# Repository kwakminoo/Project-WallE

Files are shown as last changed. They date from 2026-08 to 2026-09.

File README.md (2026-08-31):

# Project-WallE / 월이(WOLI)

스마트폰을 로봇 머리에 거치하면 집중 모드로 전환되는 **디지털 디톡스 로봇** 프로젝트입니다.  
중요한 연락은 남기고, 불필요한 연결만 잠시 끊도록 돕는 집중 동반 로봇입니다.

> 슬로건: **집중할 땐 함께, 쉴 땐 자유롭게.**

---

## 프로젝트 한눈에 보기

| 구분 | 내용 |
|---|---|
| 제품명 | 월이 (WOLI) |
| 앱 | Android (Kotlin + Jetpack Compose) |
| 펌웨어 | ESP32 (Arduino / PlatformIO, NimBLE) |
| 통신 | BLE (Bluetooth Low Energy) |
| 현재 단계 | **1차 기능 완성 + 실기기 검증 보강 단계** — 중요 연락처, 음성 명령, 백그라운드 집중 보호, BLE 잠금/캘리브레이션, 하드웨어 진단 화면까지 구현 |

### 핵심 아이디어

1. 앱에서 집중 시간·중요 연락처를 설정한다.
2. 스마트폰을 월이 머리 거치대에 **가로**로 올린다.
3. BLE 연결 후 물리적 잠금이 작동하고, 화면은 **눈만 보이는 집중 모드**가 된다.
4. 중요 연락·손 접근 시에만 표정/TTS로 안내하고, 음성으로 답장/전화 제어를 시도한다.
5. 중도 해제 시 리듬 미션 등 마찰 장치를 거친다.

자세한 기획은 루트의 `디지털_디톡스_로봇_월이_기획안.md`와 `SW 예 상시나리오.png`를 참고하세요.

---

## 현 화면 상태

에뮬레이터(Pixel_9a)에서 캡처한 초기 화면입니다. 현재 코드는 캡처 이후 알림/답장/전화 감지/BLE/타이머 기능이 추가된 상태입니다.
원본 이미지는 [`docs/screenshots/`](docs/screenshots/)에 있습니다.

### 세로 — 집중 전

| 화면 | 미리보기 |
|---|---|
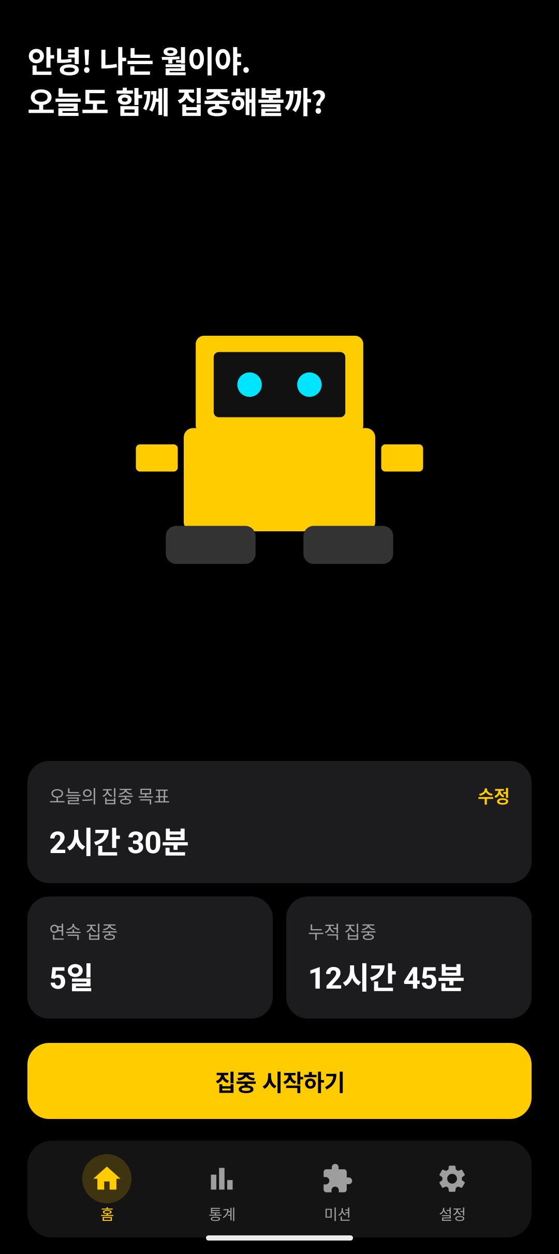
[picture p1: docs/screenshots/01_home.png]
홈
| 홈 |  |
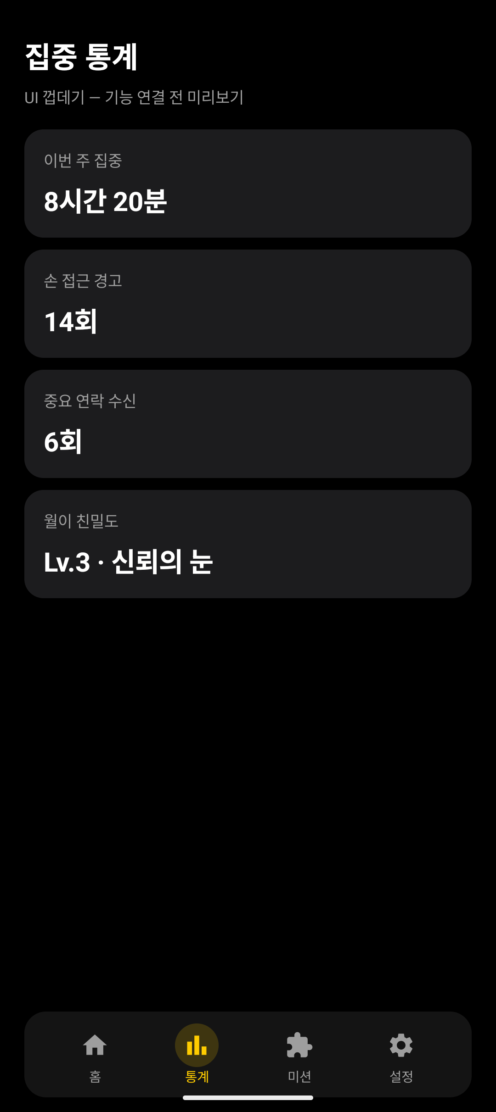
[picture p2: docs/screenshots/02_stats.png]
통계
| 통계 |  |
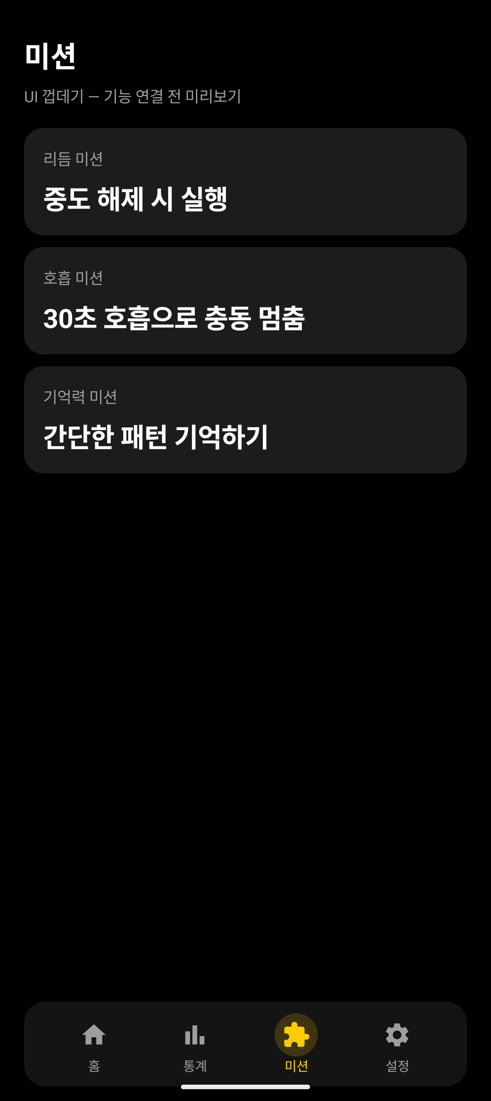
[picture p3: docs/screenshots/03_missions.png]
미션
| 미션 |  |
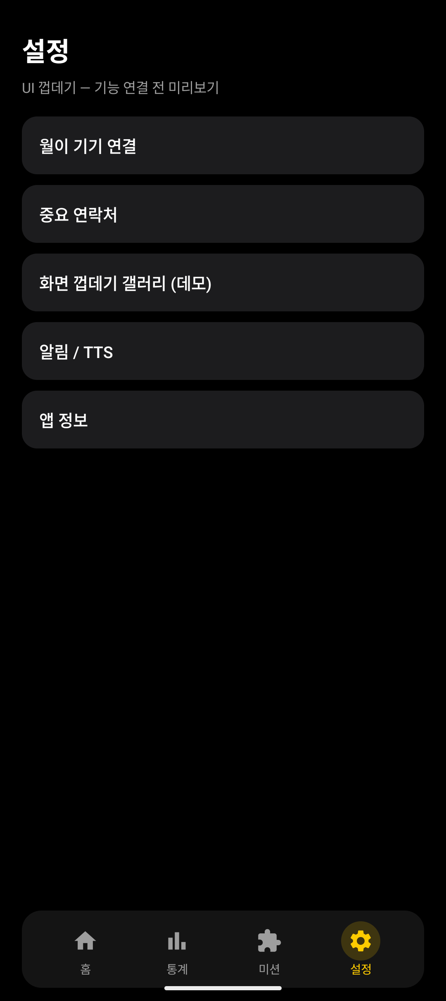
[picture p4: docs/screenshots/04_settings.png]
설정
| 설정 |  |
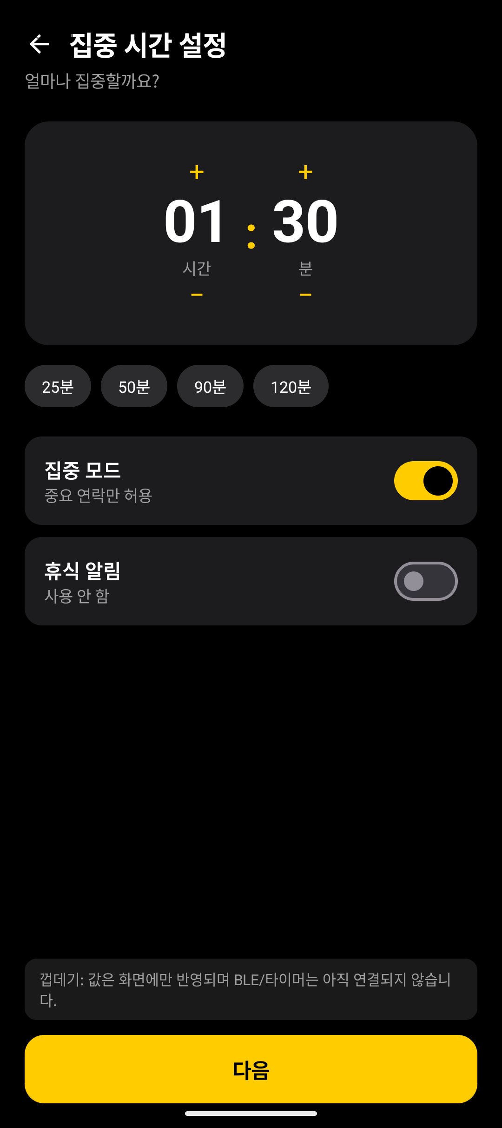
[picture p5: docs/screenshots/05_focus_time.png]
집중 시간 설정
| 집중 시간 설정 |  |
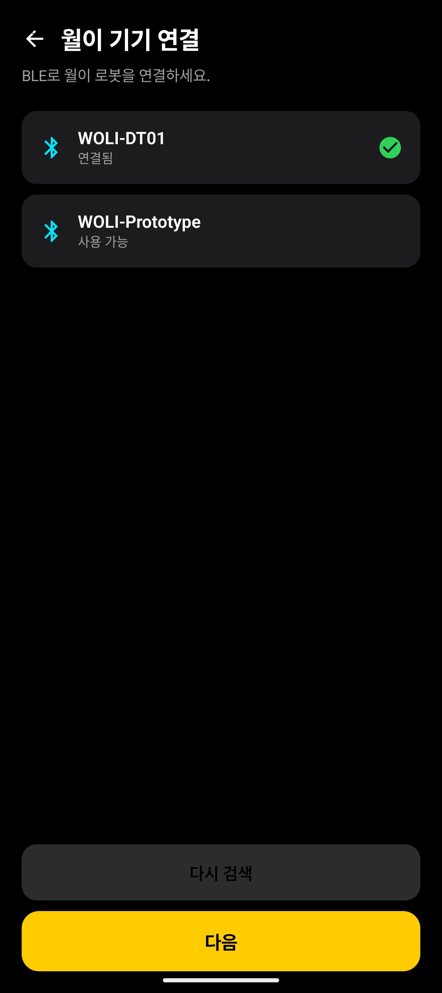
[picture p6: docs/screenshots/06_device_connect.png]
월이 기기 연결
| 월이 기기 연결 |  |
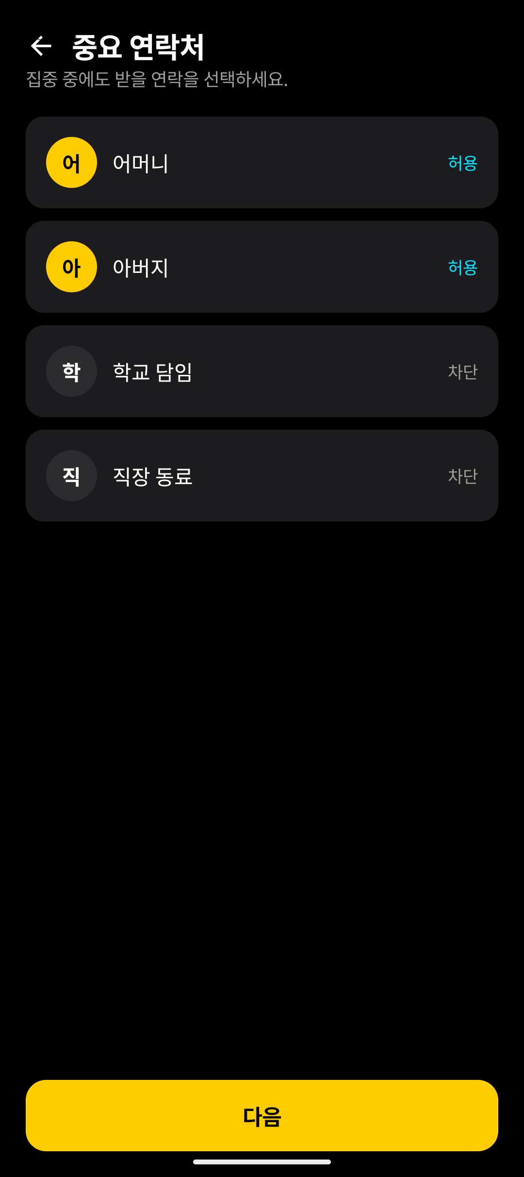
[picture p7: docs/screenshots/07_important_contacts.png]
중요 연락처
| 중요 연락처 |  |
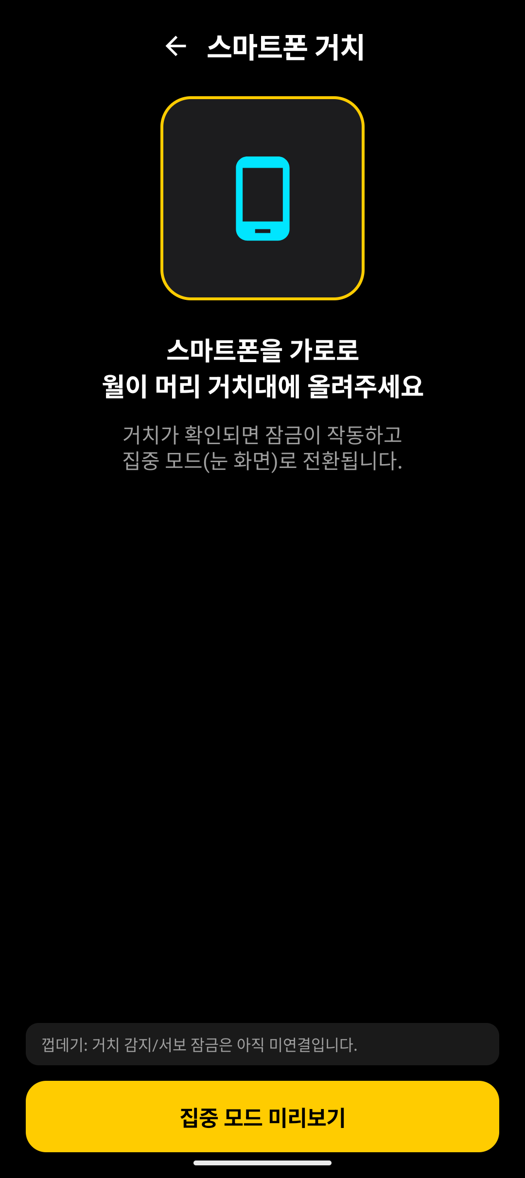
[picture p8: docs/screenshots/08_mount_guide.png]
스마트폰 거치 안내
| 스마트폰 거치 안내 |  |
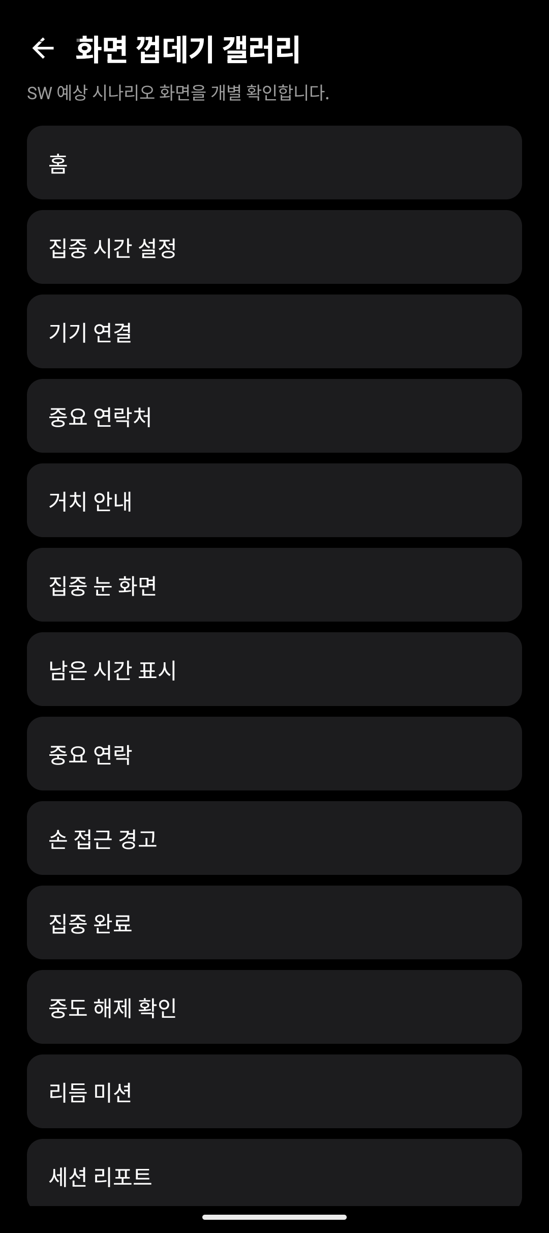
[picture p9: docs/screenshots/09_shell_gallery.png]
화면 상태 갤러리
| 화면 상태 갤러리 |  |

### 집중 모드 · 이벤트

| 화면 | 미리보기 |
|---|---|
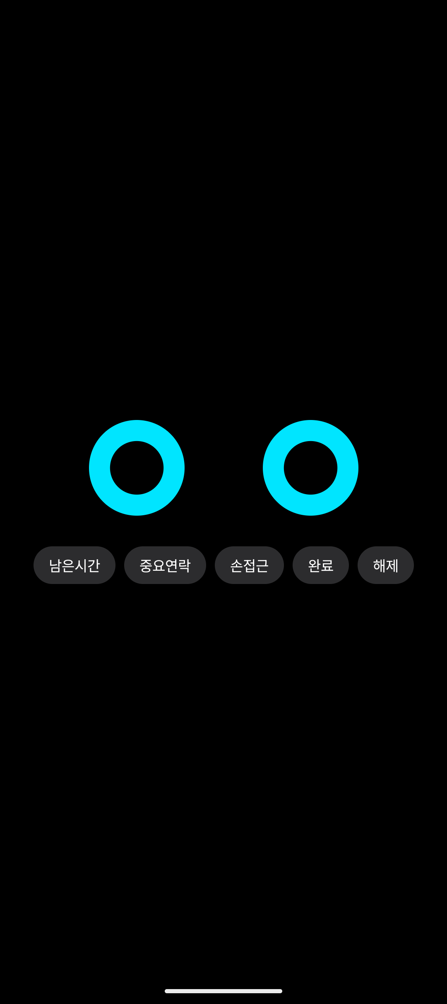
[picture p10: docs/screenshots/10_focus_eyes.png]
집중 눈 화면
| 집중 눈 화면 |  |
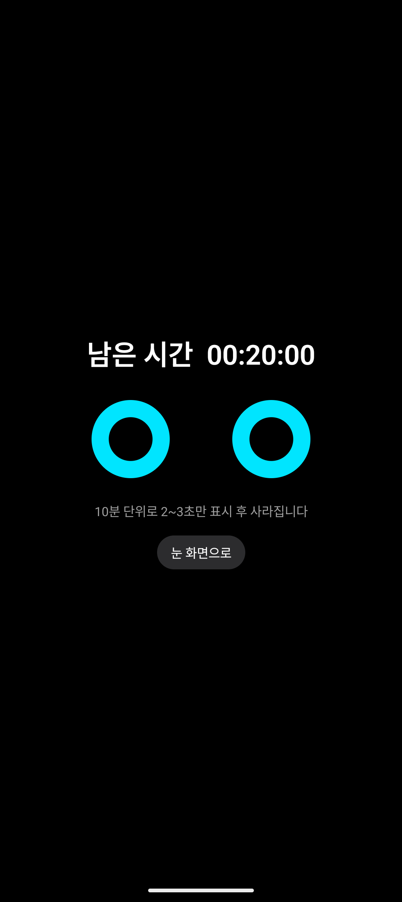
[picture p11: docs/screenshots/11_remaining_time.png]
남은 시간 표시
| 남은 시간 표시 |  |
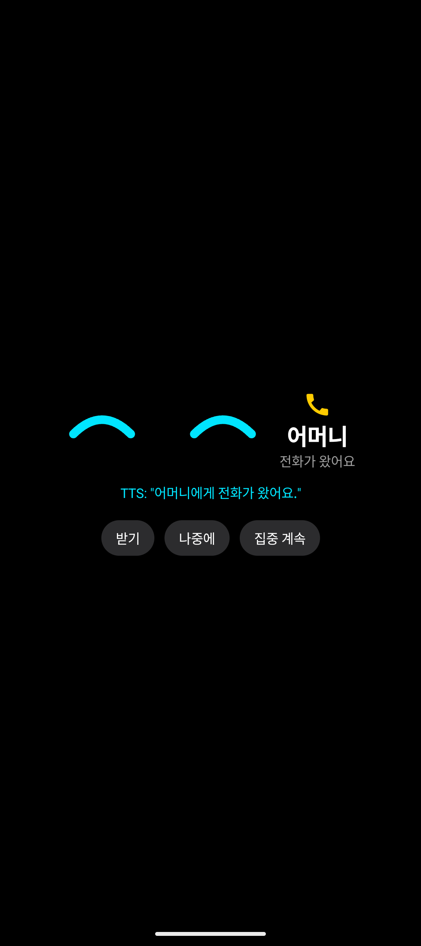
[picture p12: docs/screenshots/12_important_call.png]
중요 연락
| 중요 연락 |  |
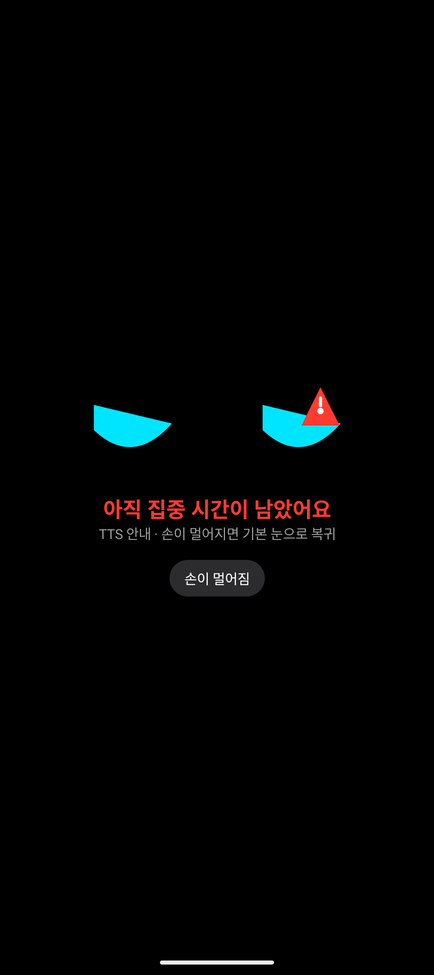
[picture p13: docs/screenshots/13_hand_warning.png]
손 접근 경고
| 손 접근 경고 |  |
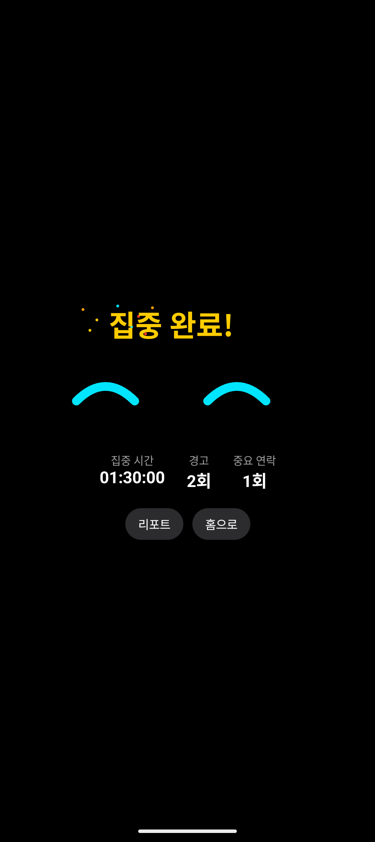
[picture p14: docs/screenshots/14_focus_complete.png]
집중 완료
| 집중 완료 |  |
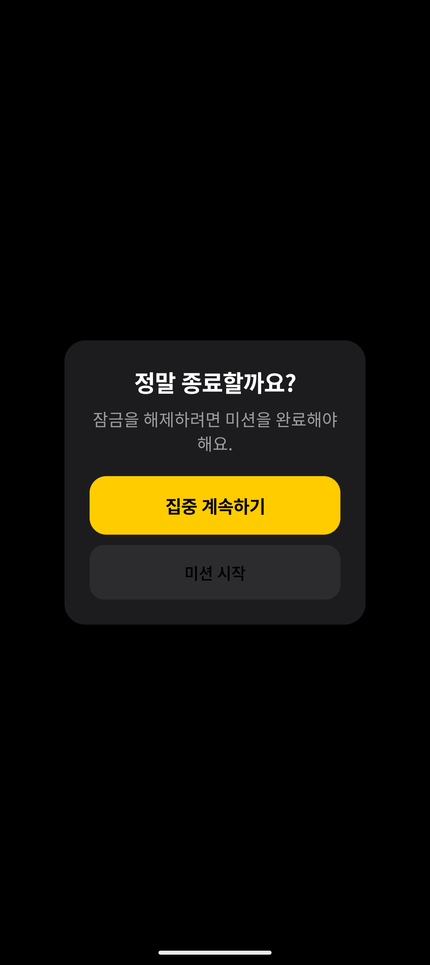
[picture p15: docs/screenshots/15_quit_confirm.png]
중도 해제 확인
| 중도 해제 확인 |  |
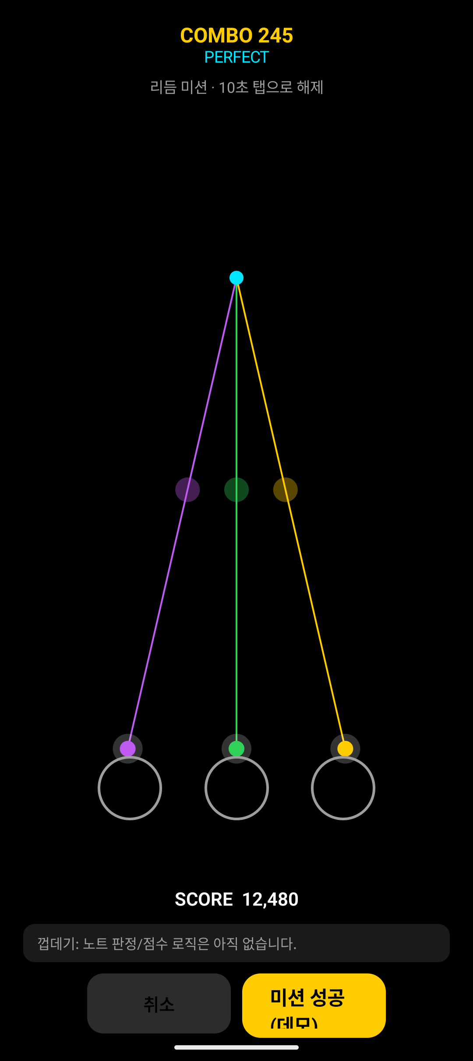
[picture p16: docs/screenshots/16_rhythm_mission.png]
리듬 미션
| 리듬 미션 |  |
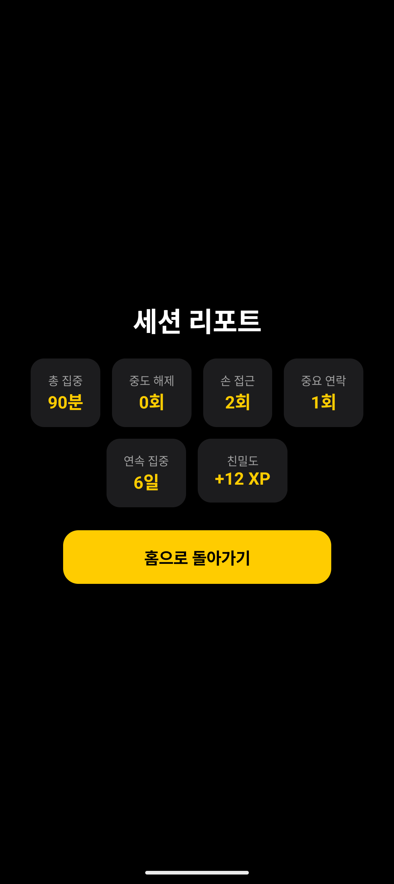
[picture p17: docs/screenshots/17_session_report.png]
세션 리포트
| 세션 리포트 |  |

---

## 저장소 구조

```text
Project-WallE/
├── android/                 # Android 앱 (Compose + 알림/전화/BLE/세션 로직)
├── firmware/                # ESP32 PlatformIO BLE GATT 펌웨어
├── docs/screenshots/        # 현 화면 상태 캡처
├── docs/RELEASE_CHECKLIST.md # APK/펌웨어 릴리즈 전 검증 항목
├── docs/PRIVACY_NOTICE.md    # 개인정보·권한 사용 안내
├── docs/DEMO_CHECKLIST.md    # 3-5분 발표/시연 순서
├── docs/ESP32_BLE_HARDWARE_TEST.md # ESP32 BLE 실기기·nRF Connect 검증
├── 디지털_디톡스_로봇_월이_기획안.md
├── SW 예 상시나리오.png
├── HW 구상도.png
├── 월E 구상도.png
└── README.md
```

---

## 개발 시작하기 (처음 clone 한 경우)

### 0) 공통

- Git, GitHub 계정
- 이 저장소 clone:

```bash
git clone https://github.com/kwakminoo/Project-WallE.git
cd Project-WallE
```

### 1) Android 앱

#### 필수 설치

1. **JDK 17** (Temurin / Oracle 등)
2. **Android Studio** (권장: Ladybug 이상) 또는 Android SDK Command-line Tools
3. Android SDK
   - `platforms;android-36` (또는 35+)
   - `build-tools;35.0.0` 이상
   - Platform-Tools

#### SDK 경로 설정

`android/local.properties` 파일을 만들고 SDK 경로를 적습니다.  
(이 파일은 git에 올리지 않습니다.)

```properties
sdk.dir=C\:\\Users\\<YOU>\\AppData\\Local\\Android\\Sdk
```

macOS/Linux 예:

```properties
sdk.dir=/Users/<YOU>/Library/Android/sdk
```

#### 의존성 / 패키지 (Gradle이 자동 다운로드)

앱 모듈(`android/app/build.gradle.kts`)에 포함된 주요 의존성:

| 용도 | 패키지 |
|---|---|
| UI | Jetpack Compose BOM, Material3, Material Icons |
| 네비게이션 | `androidx.navigation:navigation-compose` |
| 생명주기 | `lifecycle-runtime-ktx`, `lifecycle-viewmodel-compose` |
| 로컬 저장 | SharedPreferences 기반 집중 세션, 중요 연락처, 답장 이력 |
| 비동기 | `kotlinx-coroutines-android` |
| BLE | Android BLE scan/connect + WOLI GATT command/status/session/calibration |

설치/동기화:

```bash
cd android
.\gradlew.bat :app:testDebugUnitTest
.\gradlew.bat :app:assembleDebug
.\gradlew.bat lint
```

Android Studio를 쓰는 경우:

1. **Open** → `Project-WallE/android` 폴더 선택
2. Gradle Sync 완료 대기
3. 에뮬레이터 또는 실기기에서 `app` Run

#### 구현된 앱 기능

- 집중 시간 설정과 실제 세션 타이머
- 중요 연락처 수동 저장, 단말 연락처 불러오기, 이름/번호 기반 중요도 매칭
- Android 알림 접근 기반 중요 알림 감지/TTS
- `집중 우선 / 균형 / 시연` 모드 기반 알림 판단 정책
- 일반 카카오톡/문자/DM 기본 제외, 중요 연락처·긴급 표현·허용 앱만 안내
- 답장 가능한 알림의 음성 인식 초안 생성, 음성 명령, RemoteInput 전송
- 답장 전송 이력 저장과 앱별 검증 대시보드
- 전화 수신 상태 감지, 발신자 best-effort 식별, TTS 안내, 받기/거절 API 시도
- Foreground Service 기반 백그라운드 집중 보호
- Android 13+ 포그라운드 알림 권한과 배터리 최적화 상태 점검
- BLE 월이 기기 검색/연결, 시뮬레이션 연결, status 동기화, `START`/`SESSION_END`/잠금/캘리브레이션 명령
- 설정 화면의 하드웨어 검증 도구
- 거치/잠금/손 접근 상태 반영
- 리듬/호흡/기억력 미션
- 세션 완료 리포트와 통계 일부 실제 데이터 반영

### 2) ESP32 펌웨어

#### 필수 설치

1. [VS Code](https://code.visualstudio.com/) + **PlatformIO** 확장  
   또는 [PlatformIO Core CLI](https://platformio.org/install/cli)
2. USB 드라이버 (보드에 따라 CP210x / CH340)

#### 의존성

`firmware/platformio.ini` 기준:

- platform: `espressif32`
- board: `esp32dev` (ESP32-WROOM-32)
- framework: `arduino`
- lib: `h2zero/NimBLE-Arduino`, `madhephaestus/ESP32Servo`

빌드/업로드:

```bash
cd firmware
pio pkg install
pio run
pio run -t upload
pio device monitor
```

현재 `src/main.cpp`는 WOLI BLE GATT 서버를 실행합니다.

| 항목 | 값 |
|---|---|
| BLE 이름 | `WOLI-DT01` |
| Service UUID | `7e7a0001-1f5f-4c2b-9b6f-2d1b7f4f0100` |
| Command UUID | `7e7a0002-1f5f-4c2b-9b6f-2d1b7f4f0100` |
| Status UUID | `7e7a0003-1f5f-4c2b-9b6f-2d1b7f4f0100` |
| Commands | `LOCK`, `UNLOCK`, `START`, `SESSION_END`, `STOP`, `STATUS`, `CAL_LOCK=90`, `CAL_UNLOCK=10` |
| Status payload | `mount=1;lock=1;hand=0;battery=100;session=1` |

`START`는 집중 세션과 잠금을 활성화하고, 정상 완료의 `SESSION_END`는 세션을 비활성화하고 잠금을 풉니다. Status Characteristic은 READ + NOTIFY이며 `session`은 집중 세션 활성 상태(0/1)입니다.

ESP32 핀 연결, Android 실기기 절차, 재연결, nRF Connect 분리 검증은 [ESP32 BLE 실기기 검증](docs/ESP32_BLE_HARDWARE_TEST.md)을 따르세요.

### 3) (선택) 설계 도구

| 영역 | 도구 |
|---|---|
| UI·UX | Figma |
| 3D 모델링 | Fusion 360 / Onshape |
| 렌더링 | Blender |

---

## MVP 범위 (참고)

**1차 MVP:** 앱 실행, 집중 시간, BLE, 서보 잠금, 눈 화면, 남은 시간 표시, 중요 알림/전화, 음성 답장/명령, 완료/리포트

**현재 저장소:** 1차 MVP 소프트웨어 구현 + ESP32 BLE GATT/Servo 펌웨어 + 기획 문서

### 실기기 검증 체크리스트

- 설정 > 집중 알림 기준에서 `균형` 모드와 허용 앱 상태 확인
- Android 실기기에서 카카오톡/문자/Telegram/WhatsApp 답장 성공 여부 확인
- 일반 메신저 알림은 제외되고 중요 연락처/긴급 알림만 TTS 안내되는지 확인
- Android 제조사별 발신자 번호 전달, 전화 받기/거절 API 허용 여부 확인
- 실제 서보 각도, 리미트 스위치, 손 접근 센서 핀/전기적 안정성 캘리브레이션
- 실제 BLE `START`/`SESSION_END`, Status Notify, 연결 해제 후 상태 재동기화 검증
- Foreground Service 알림 권한과 배터리 최적화 예외 동작 확인
- 최신 UI 상태에 맞춘 스크린샷 재촬영

자세한 제출 전 점검은 [`docs/RELEASE_CHECKLIST.md`](docs/RELEASE_CHECKLIST.md), [ESP32 BLE 실기기 검증](docs/ESP32_BLE_HARDWARE_TEST.md), 알림 판단 기준은 [`docs/NOTIFICATION_POLICY.md`](docs/NOTIFICATION_POLICY.md), 개인정보 안내는 [`docs/PRIVACY_NOTICE.md`](docs/PRIVACY_NOTICE.md), 시연 흐름은 [`docs/DEMO_CHECKLIST.md`](docs/DEMO_CHECKLIST.md)를 확인하세요.

---

## GitHub

- 원격 저장소: https://github.com/kwakminoo/Project-WallE

대용량/비관련 파일(`TNC Web Re.zip` 등)은 `.gitignore`로 제외합니다.

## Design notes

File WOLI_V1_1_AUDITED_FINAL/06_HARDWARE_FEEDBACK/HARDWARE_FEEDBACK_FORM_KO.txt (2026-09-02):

WOLI V1.1 HARDWARE FEEDBACK FORM
================================

DATE:
PRINTER:
FILAMENT:
LAYER:

A. MAIN CHASSIS / MOTOR
N20 bracket fit: PASS / FAIL
Wheel free rotation: PASS / FAIL
Actual ground clearance:
Photo:

B. BATTERY
Tray fit: PASS / FAIL
68×143×11 battery fit: PASS / FAIL
Port access: PASS / FAIL
Correction mm:
Photo:

C. CASTER
Clip-fit: PASS / FAIL
Retainer: PASS / FAIL
Ball free rotation: PASS / FAIL
Ground contact with both drive wheels: PASS / FAIL
Shim: 0 / 1 / 2 / 3mm
Photo:

D. TOP COVER / TOF
Skirt insertion: PASS / FAIL
Side screws: PASS / FAIL
ToF opening alignment: PASS / FAIL
Wire pinch: PASS / FAIL

E. PHONE BALL
Diameter:
Fit:
Sag:
Photo:

F. SERVO LOCK
Horn photo:
Horn hole/screw:
Chosen reach:
LOCK:
UNLOCK:
Stall:
Interference:

G. ELECTRONICS
PCB tray:
TB6612 tray:
USB holder:
USB hatch if tested:

H. STABILITY
Phone model:
Approx phone mass:
Standing:
Driving:
Hard stop:
Turning:

I. ERROR
File:
Symptom:
Actual mm:
CAD mm:
Requested change:
Photo:

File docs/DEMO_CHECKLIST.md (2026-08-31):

# WOLI 시연 체크리스트

3-5분 발표 기준의 안정적인 데모 순서입니다.

## 1. 시작 전

- [ ] 테스트 연락처를 중요 연락처에 저장한다.
- [ ] 설정 > 집중 알림 기준에서 `균형` 모드를 선택한다.
- [ ] 답장 시연까지 필요하면 허용 앱 또는 `시연` 모드를 준비한다.
- [ ] 테스트 메시지 앱에서 알림이 뜨도록 준비한다.
- [ ] 앱 설정 > 알림 / TTS 검증에서 알림 접근과 TTS 상태를 확인한다.
- [ ] 앱 설정 > 하드웨어 검증에서 ESP32 또는 시뮬레이션 연결을 확인한다.
- [ ] 서보 잠금/해제 각도가 안전한지 확인한다.
- [ ] 실기기 시연이면 [ESP32 BLE 실기기 검증](ESP32_BLE_HARDWARE_TEST.md)의 배선과 STATUS 동기화를 먼저 확인한다.

## 2. 발표 흐름

1. 홈에서 오늘의 집중 목표를 보여준다.
2. 집중 시간을 25분 또는 50분으로 설정한다.
3. 월이 기기를 연결하거나 시뮬레이션으로 연결한다.
4. 중요 연락처를 보여주고, 집중 중 허용할 연락만 남긴다는 점을 설명한다.
5. 설정 > 집중 알림 기준에서 일반 메신저는 제외되고 중요 연락처/긴급/허용 앱만 안내된다고 설명한다.
6. 집중 알림 전달 화면에서 알림 접근, 포그라운드 알림, 전화 권한 상태를 확인한다.
7. 하드웨어 검증 화면에서 `STATUS`와 mount/lock/hand/battery/session 상태를 보여준다.
8. 스마트폰 거치 입력을 바꿔 `mount=1` Notify가 반영되는 것을 보여준다.
9. 짧은 시연 세션을 시작해 `START` 뒤 `lock=1`, `session=1`과 집중 눈 화면을 보여준다.
10. 테스트 알림 또는 전화 이벤트를 발생시켜 TTS 안내와 답장/전화 제어 흐름을 보여준다.
11. 손 접근 입력을 한 번 감지해 경고 화면과 손 접근 횟수 +1을 보여주고, 감지를 유지해도 횟수가 더 늘지 않는 것을 보여준다.
12. 손 접근을 해제해 `hand=0` Notify 뒤 기본 집중 눈 화면으로 자동 복귀하는 것을 보여준다.
13. 정상 완료 시 `SESSION_END` 뒤 `lock=0`, `session=0`, 집중 완료 화면과 세션 리포트를 보여준다. 중도 종료는 기존 미션 흐름으로만 설명한다.

## 3. 실패 대비

- ESP32 연결 실패: 설정 > 하드웨어 검증에서 `WOLI-Simulator`로 연결한다.
- 메시지 답장 실패: 설정 > 알림 / TTS 검증에서 앱별 성공/실패 이력을 보여준다.
- 일반 메신저가 안내되지 않음: 설정 > 집중 알림 기준에서 허용 앱 또는 `시연` 모드를 켠다.
- 전화 제어 실패: Android 정책상 일부 기기에서 best-effort라고 설명하고 수신 감지/TTS 안내를 중심으로 시연한다.
- 알림 미수신: 알림 접근 설정과 앱 알림 설정을 다시 열어 확인한다.
- TTS 출력 실패: 기기 볼륨과 미디어 출력 장치를 확인하고, 화면 이벤트 흐름으로 대체한다.
- BLE 연결 해제: `WOLI-DT01`을 다시 검색해 연결한 뒤 하드웨어 검증의 `STATUS`로 실제 상태를 다시 동기화한다. 시뮬레이션은 실기기 BLE/센서 검증의 대체 증거가 아니다.

## 4. 심사위원에게 강조할 포인트

- 집중을 방해하는 스마트폰 자체를 물리적으로 멀리 두는 로봇형 UX
- 모든 연락을 차단하지 않고 중요한 연락만 선별하는 현실적인 디지털 디톡스
- 일반 카톡/문자를 기본 제외해 집중 목적을 해치지 않는 알림 정책
- 알림, 전화, BLE, 서보, 센서 상태가 하나의 집중 세션으로 연결되는 점
- Android 정책 차이를 앱별 검증 대시보드와 시뮬레이션 경로로 투명하게 다루는 점

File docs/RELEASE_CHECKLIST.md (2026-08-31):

# WOLI 1차 릴리즈 체크리스트

월이 앱과 ESP32 펌웨어를 시연 가능한 상태로 고정하기 위한 체크리스트입니다.

## 1. Android 빌드

- [ ] `android/local.properties`에 실제 Android SDK 경로가 있다.
- [ ] 디버그 빌드가 성공한다.

```bash
cd android
.\gradlew.bat :app:testDebugUnitTest
.\gradlew.bat :app:assembleDebug
.\gradlew.bat lint
```

macOS/Linux에서는 `./gradlew :app:testDebugUnitTest :app:assembleDebug lint`를 사용합니다.

- [ ] APK 위치를 확인한다.

```text
android/app/build/outputs/apk/debug/app-debug.apk
```

## 2. 릴리즈 서명

`local.properties`나 환경 변수로만 서명 정보를 관리하고, 키스토어와 비밀번호는 git에 올리지 않습니다.

권장 환경 변수:

```bash
export WOLI_STORE_FILE=/absolute/path/woli-release.jks
export WOLI_STORE_PASSWORD=...
export WOLI_KEY_ALIAS=woli
export WOLI_KEY_PASSWORD=...
```

릴리즈 빌드 설정을 추가한 뒤 다음 명령으로 확인합니다.

```bash
cd android
./gradlew :app:assembleRelease
```

## 3. Android 실기기 권한

- [ ] 알림 접근: 설정 > 알림 접근 > 월이 허용
- [ ] 앱 알림: Android 13 이상에서 월이 알림 허용
- [ ] 배터리 제한: 설정 > 배터리 최적화에서 월이를 제한 없음 또는 예외로 설정
- [ ] 전화 감지: 전화 상태 권한 허용
- [ ] 발신자 식별: 통화 기록 권한은 기기/OS 정책에 따라 선택 허용
- [ ] 전화 제어: 받기/거절 API가 허용되는 기기에서만 검증
- [ ] 연락처: 중요 연락처 매칭에 필요한 경우만 허용
- [ ] Bluetooth: ESP32 실기기 연결 전 허용

앱 내부 확인 위치:

- 설정 > 집중 알림 기준
- 설정 > 알림 / TTS 검증
- 설정 > 하드웨어 검증
- 집중 시작 플로우 > 집중 알림 전달

## 4. 앱별 답장 검증

앱마다 RemoteInput 지원 방식이 다릅니다. 아래는 실기기에서 직접 확인해야 합니다.

- [ ] SMS 또는 기본 메시지 앱
- [ ] KakaoTalk
- [ ] Telegram
- [ ] WhatsApp

검증 기준:

- [ ] 설정 > 집중 알림 기준 기본값이 `균형` 모드로 표시된다.
- [ ] 일반 카카오톡/문자/DM은 기본적으로 TTS 안내되지 않는다.
- [ ] 중요 연락처의 카카오톡/문자/DM은 TTS 안내된다.
- [ ] 중요 연락처 + 긴급 표현 메시지는 긴급 알림으로 표시된다.
- [ ] 광고/쿠폰/좋아요/댓글/묶음/재생 중 알림은 TTS 안내되지 않는다.
- [ ] `시연` 모드에서 답장 가능한 테스트 메시지가 안내된다.
- [ ] 알림 제목/본문이 개인정보 마스킹 없이 과도하게 저장되지 않는다.
- [ ] 월이가 TTS로 중요 알림만 안내한다.
- [ ] 음성 명령 `답장`, `보내`, `취소`가 의도대로 동작한다.
- [ ] 전송 성공/실패가 설정 > 알림 / TTS 검증에 남는다.

## 5. ESP32 펌웨어

- [ ] PlatformIO가 설치되어 있다.
- [ ] 빌드가 성공한다.

```bash
cd firmware
pio pkg install
pio run
```

- [ ] 업로드가 성공한다.

```bash
pio run -t upload
pio device monitor
```

- [ ] BLE 이름이 `WOLI-DT01`로 보인다.
- [ ] 앱의 설정 > 하드웨어 검증에서 `STATUS`, `LOCK`, `UNLOCK`, `START`, `SESSION_END`, `CAL_LOCK`, `CAL_UNLOCK` 명령이 동작한다.
- [ ] `START` 후 Status가 `lock=1;session=1`을, 정상 완료의 `SESSION_END` 후 `lock=0;session=0`을 보고한다.
- [ ] Status Characteristic의 READ + NOTIFY로 mount/lock/hand/battery/session이 실제 상태와 일치한다.
- [ ] GPIO 19 거치 입력과 GPIO 21 손 접근 입력이 debounce 후 즉시 Notify된다. 손을 유지해도 세션 경고 횟수는 증가하지 않고, 손을 떼면 집중 눈 화면으로 복귀한다.
- [ ] 집중 중 연결을 끊고 다시 연결한 뒤 `STATUS` 동기화가 정상이며 앱 타이머/세션 기록이 유지된다.
- [ ] nRF Connect에서 Command Write와 Status Read + Notify를 별도로 확인했다.

세부 배선, 안전 주의, STEP 1–15, nRF Connect 절차는 [ESP32 BLE 실기기 검증](ESP32_BLE_HARDWARE_TEST.md)을 따른다.

## 6. 시연 전 고정

- [ ] 스마트폰 1대, 예비 스마트폰 1대, USB-C 케이블, 보조배터리를 준비한다.
- [ ] ESP32 전원 공급이 흔들리지 않는다.
- [ ] 서보 잠금 각도가 스마트폰을 무리하게 누르지 않는다.
- [ ] 발표용 연락처와 테스트 메시지만 사용한다.
- [ ] 개인정보가 들어간 실제 알림은 방해 금지 또는 별도 계정으로 차단한다.
- [ ] 네트워크가 없어도 핵심 시연이 가능한 시뮬레이션 경로를 준비한다.

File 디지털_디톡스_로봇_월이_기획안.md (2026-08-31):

# 디지털 디톡스 로봇 ‘월이(WOLI)’ 기획안

> **한 줄 정의**  
> 스마트폰을 빼앗는 장치가 아니라, 중요한 연결은 남기고 불필요한 연결만 잠시 끊어주는 집중 동반 로봇

---

## 1. 프로젝트 개요

‘월이’는 스마트폰을 로봇 머리 부분의 거치대에 장착하면 전용 앱이 자동으로 집중 모드로 전환되는 디지털 디톡스 로봇이다.  
사용자는 집중 시간을 설정하고 스마트폰을 가로 방향으로 거치한다. 집중 중에는 스마트폰 화면이 월이의 얼굴이 되어 눈 모양만 표시되며, 중요한 연락이나 손 접근 상황에서만 표정과 음성 안내가 나타난다.

월이의 핵심은 별도의 디스플레이·마이크·스피커를 추가하지 않고 스마트폰의 화면, 전면 카메라, 근접 감지 기능, 마이크, 스피커, 알림 기능을 그대로 활용하는 것이다. 로봇 하드웨어는 스마트폰 거치, 물리적 잠금, BLE 연결, 전원 공급 등 최소 기능을 담당하며, 이번 실기기 검증 단계에서는 거치·손 접근 상태를 ESP32의 교체 가능한 디지털 입력으로 앱에 전달한다.

---

## 2. 문제 정의

스마트폰 사용자는 공부나 업무를 시작한 뒤에도 SNS, 메신저, 짧은 영상, 게임, 반복적인 알림 확인으로 인해 집중 흐름이 쉽게 끊긴다.

기존 집중 앱은 사용자가 직접 앱을 종료하거나 다른 앱으로 이동할 수 있어 통제력이 약하다. 반대로 타이머형 잠금 상자는 스마트폰을 완전히 차단하기 때문에 긴급 전화나 중요한 알림까지 놓칠 수 있다. 또한 단순한 차단 방식은 사용자가 집중을 ‘통제’로 인식하게 만들어 장기적인 습관 형성으로 이어지기 어렵다.

월이는 다음 문제를 해결한다.

- 앱만으로는 부족한 자기 통제
- 긴급 연락까지 차단되는 불안
- 집중 시간 중 반복적으로 스마트폰에 손을 대는 습관
- 집중 앱의 낮은 지속 사용 동기
- 단순 타이머가 제공하지 못하는 감정적 상호작용

---

## 3. 고객 타깃층

### 3.1 핵심 타깃

#### 학생·수험생
- 공부 중 SNS와 영상 앱을 반복적으로 확인하는 사용자
- 25분~120분 단위로 집중 시간을 관리하는 사용자
- 일반 타이머보다 캐릭터와 시각적 피드백을 선호하는 사용자

#### 직장인·재택근무자·프리랜서
- 문서 작성, 코딩, 디자인 등 몰입 업무가 필요한 사용자
- 업무 중 메신저와 알림 때문에 집중이 자주 끊기는 사용자
- 중요한 연락만 놓치지 않고 싶은 사용자

#### 디지털 웰니스 관심 사용자
- 자기 전 스마트폰 사용을 줄이려는 사용자
- 독서, 운동, 명상 등 오프라인 습관을 만들고 싶은 사용자
- 디지털 디톡스를 강제 차단이 아닌 재미있는 경험으로 만들고 싶은 사용자

### 3.2 확장 타깃

- 스터디카페 및 도서관
- 기업 사내 집중·웰니스 프로그램
- 부모와 자녀가 함께 사용하는 가정용 집중 기기
- 학교 자기주도학습 프로그램

---

## 4. 핵심 기능

### 4.1 스마트폰 거치 및 자동 집중 모드

사용자가 앱에서 집중 시간을 설정한 뒤 스마트폰을 월이의 머리 부분에 가로로 거치하면 집중 모드가 시작된다.

- 앱 실행
- 집중 시간 설정
- 스마트폰 가로 거치
- BLE 연결 확인
- 집중 모드 자동 시작
- 물리적 잠금 작동

### 4.2 월이 얼굴 화면

집중 모드에서는 스마트폰 화면 전체가 검은색 배경으로 전환되고 월이의 눈만 표시된다.

#### 기본 화면
- 검은색 배경
- 청록색 또는 하늘색 눈 2개
- 타이머, 버튼, 문구는 기본적으로 숨김
- 화면을 로봇의 얼굴처럼 사용

#### 10분 단위 남은 시간 표시
집중 시간이 10분 단위로 줄어드는 순간에만 남은 시간을 짧게 표시한다.

예시:

- 50분 남음
- 40분 남음
- 30분 남음
- 20분 남음
- 10분 남음

남은 시간은 약 2~3초간 표시된 뒤 사라지고 다시 눈만 보이는 기본 화면으로 돌아간다.

### 4.3 손 접근 감지

이번 실기기 검증 단계에서는 ESP32의 디지털 손 접근 입력을 BLE `hand` 상태로 전달한다. 센서 모델은 고정하지 않으며, 스마트폰 전면 카메라·근접 센서·영상 인식은 이후 보조 입력으로 확장할 수 있다.

- 손이 가까워지면 월이의 눈이 사용자를 따라감
- 일정 거리 이상 접근하면 경계 표정 표시
- “아직 집중 시간이 남았어요”라는 음성 안내
- 손이 멀어지면 기본 눈 화면으로 복귀
- 접근 횟수를 집중 리포트에 기록

### 4.4 중요 연락 전달

사용자는 집중 시작 전에 허용 연락처와 중요 알림을 설정한다.

- 가족
- 학교 또는 직장
- 특정 연락처
- 긴급 전화
- 선택한 메신저 또는 알림 유형

중요 연락이 오면 월이는 잠시 놀란 표정으로 바뀌고 스마트폰 스피커로 내용을 안내한다.

예시:

> “어머니에게 전화가 왔어요.”

사용자는 음성 명령 또는 화면 버튼으로 다음 행동을 선택한다.

- 받기
- 나중에 확인
- 집중 계속

### 4.5 중도 해제 방지 미션

사용자가 집중 시간을 채우기 전에 스마트폰을 꺼내거나 앱을 종료하려 하면 해제 미션이 실행된다.

미션 예시:

- 리듬 게임
- 30초 호흡 미션
- 간단한 기억력 게임
- 집중 종료 이유 선택
- 긴급 해제 버튼 길게 누르기

미션은 완전한 강제 차단이 아니라 충동적인 해제를 한 번 더 생각하게 만드는 행동 마찰 장치로 사용한다.

### 4.6 집중 완료 및 리포트

집중 시간이 끝나면 월이의 눈이 웃는 표정으로 바뀌고 완료 음성이 재생된다.

제공 정보:

- 총 집중 시간
- 중도 해제 횟수
- 손 접근 횟수
- 중요 연락 수신 횟수
- 연속 집중 일수
- 일·주·월별 집중 시간
- 월이 친밀도 또는 성장 단계

---

## 5. 예상 화면 시나리오

### 5.1 세로 화면 단계

1. 홈 화면
2. 월이 기기 연결
3. 집중 시간 설정
4. 중요 연락처 설정
5. 스마트폰 거치 안내

### 5.2 가로 화면 단계

1. 집중 시작
2. 기본 눈 화면
3. 10분 단위 남은 시간 잠깐 표시
4. 중요 연락 도착
5. 손 접근 경고
6. 집중 완료
7. 중도 해제 미션
8. 세션 리포트

### 화면 방향 원칙

- 집중 시작 전: 세로 화면
- 스마트폰 거치 후: 가로 화면
- 집중 모드 이후 모든 화면: 일반적인 스마트폰 가로 비율 유지
- 집중 기본 화면: 눈만 표시
- 시간 정보: 10분 단위에서만 잠깐 표시
- 알림·경고·완료 화면: 필요한 정보만 짧게 표시

---

## 6. 기존 제품과의 차별성

| 제품 유형 | 기존 한계 | 월이의 차별점 |
|---|---|---|
| 집중 앱 | 사용자가 쉽게 종료 가능 | 스마트폰 거치와 물리적 잠금 결합 |
| 타이머 잠금 상자 | 연락과 알림을 모두 차단 | 중요한 연락만 선별 전달 |
| 포모도로 타이머 | 시간 측정 기능 중심 | 손 접근 감지, 표정, 음성, 리포트 제공 |
| 반려 로봇 | 감성 상호작용 중심 | 집중 습관 형성에 특화 |
| 스마트폰 웰빙 기능 | 기능적이지만 지속 동기가 약함 | 미션·표정·성장 요소 제공 |

### 핵심 차별화 문장

월이는 앱, 물리적 거치, 중요한 연락 전달, 캐릭터 상호작용을 결합해 디지털 디톡스를 단순한 차단이 아니라 ‘함께 집중하는 경험’으로 전환한다.

---

## 7. 시스템 구성

```mermaid
flowchart LR
    A[사용자] --> B[월이 앱]
    B --> C[집중 시간 설정]
    C --> D[스마트폰 가로 거치]
    D --> E[BLE 연결]
    E --> F[물리적 잠금]
    F --> G[집중 모드 실행]
    G --> H[눈 화면 표시]
    H --> I{이벤트 발생}
    I -->|10분 단위| J[남은 시간 잠깐 표시]
    I -->|중요 연락| K[음성·화면 전달]
    I -->|손 접근| L[경고 표정·음성]
    I -->|시간 종료| M[집중 완료]
    M --> N[리포트 저장]
```

---

## 8. 하드웨어 구성

### 8.1 필수 하드웨어

| 부품 | 역할 | 예상 단가 |
|---|---|---:|
| ESP32-WROOM-32 개발보드 | 스마트폰 앱과 BLE 통신, 잠금장치 제어 | 약 8,000~10,000원 |
| MG90S 메탈기어 서보모터 | 스마트폰 거치대 잠금·해제 | 약 4,000~6,000원 |
| 마이크로 리미트 스위치 | 스마트폰 거치 여부 확인 | 약 500~1,000원 |
| 5V 보조배터리 | ESP32와 서보모터 전원 공급 | 약 15,000~25,000원 |
| 전원 스위치·배선·커넥터 | 전원 제어 및 내부 연결 | 약 5,000~10,000원 |
| 나사·스프링·고무 패드 | 조립 및 스마트폰 보호 | 약 3,000~7,000원 |
| 3D 프린팅 케이스 | 월이 외형, 거치대, 잠금 구조 | 약 20,000~60,000원 |

### 8.2 제외 가능한 하드웨어

센서 모델을 제품 사양으로 고정하지 않는다. 실기기 검증에는 ESP32 GPIO의 교체 가능한 디지털 손 접근 입력을 사용하며, 배선과 검증 절차는 [ESP32 BLE 실기기 검증](docs/ESP32_BLE_HARDWARE_TEST.md)을 따른다. 다음 기능은 스마트폰 자체 기능을 사용하므로 별도 부품을 추가하지 않는다.

- OLED 디스플레이
- 별도 마이크
- 별도 스피커
- 별도 알림 표시 장치
- 별도 카메라

### 8.3 예상 총비용

- 전자부품 및 전원: 약 35,000~55,000원
- 3D 프린팅 케이스 포함: 약 55,000~115,000원
- 스마트폰 및 배송비 제외

> 가격은 기획 단계의 예상치이며 판매처, 배송비, 환율, 재고에 따라 달라질 수 있다.

---

## 9. 소프트웨어 구성

### 9.1 Android 앱

- 언어: Kotlin
- UI: Jetpack Compose
- 통신: Bluetooth Low Energy
- 로컬 저장: Room 또는 DataStore
- 음성 출력: Android TTS
- 음성 입력: SpeechRecognizer
- 손 접근 상태: ESP32 BLE `hand` 상태를 받아 경고·리포트에 반영
- 알림 처리: Notification Listener
- 집중 타이머: Foreground Service
- 화면 방향: 집중 모드 진입 시 Landscape 고정
- 미션: 간단한 리듬 게임 또는 기억력 게임

### 9.2 ESP32 펌웨어

- 언어: C/C++
- 개발 도구: Arduino IDE 또는 PlatformIO
- BLE 서버
- 스마트폰 거치 감지
- 디지털 손 접근 입력과 debounce
- 서보모터 잠금·해제
- 연결 상태 확인
- 비상 해제 처리
- 배터리 상태 전달

---

## 10. 개발환경

| 영역 | 개발 도구 |
|---|---|
| Android 앱 | Android Studio, Kotlin, Jetpack Compose |
| ESP32 펌웨어 | Arduino IDE 또는 VS Code + PlatformIO |
| UI·UX 설계 | Figma |
| 3D 모델링 | Fusion 360 또는 Onshape |
| 외형 렌더링 | Blender |
| 버전 관리 | GitHub |
| 테스트 | Android 실기기, ESP32 개발보드, 3D 프린팅 시제품 |

---

## 11. 앱과 로봇의 역할 분담

### 스마트폰 앱

- 월이 얼굴 표시
- 집중 시간 관리
- BLE 손 접근 이벤트의 화면·리포트 반영
- 중요 연락 필터링
- TTS·STT
- 미션 실행
- 집중 기록과 리포트 저장
- 사용자의 모든 주요 인터페이스 제공

### 로봇 하드웨어

- 스마트폰 거치
- 디지털 손 접근 상태 전달
- 스마트폰 잠금·해제
- BLE 연결
- 물리적 존재감 제공
- 캐릭터 외형 형성
- 비상 수동 해제 제공

---

## 12. MVP 개발 범위

### 1차 MVP

- Android 앱 실행
- 집중 시간 설정
- 스마트폰 가로 거치
- BLE 연결
- 서보모터 잠금·해제
- 검은 화면과 눈 애니메이션
- 10분 단위 남은 시간 표시
- 중요 전화 알림
- 집중 완료 화면
- 기본 리포트

### 2차 개발

- 전면 카메라 기반 손 접근 감지
- 음성 명령
- 중도 해제 미션
- 월이 친밀도·성장 시스템
- 집중 통계 시각화
- 사용자별 표정 설정

### 3차 확장

- iOS 앱
- 클라우드 백업
- 스터디 그룹 기능
- 가족·학교·기업용 관리자 모드
- 월이 캐릭터 스킨
- 주행 또는 고개 움직임

---

## 13. 안전 및 설계 원칙

- 전원이 끊기면 잠금이 풀리는 Fail-open 구조
- 후면 수동 해제 레버 제공
- 배터리 부족 시 자동 잠금 해제
- 긴급 전화 시 즉시 해제 가능
- 스마트폰 화면과 프레임을 보호하는 고무 패드 적용
- 다양한 스마트폰 크기를 수용하는 슬라이드형 거치대
- 집중 방해를 줄이기 위해 기본 화면에는 눈만 표시
- 사용자를 강제로 가두는 장치가 아니라 자발적 집중을 돕는 보조기기로 설계

---

## 14. 최종 핵심 시연 흐름

```mermaid
sequenceDiagram
    participant U as 사용자
    participant A as 월이 앱
    participant R as 월이 로봇

    U->>A: 집중 시간 설정
    U->>R: 스마트폰 가로 거치
    A->>R: BLE 연결 및 START 명령
    R->>R: 스마트폰 잠금
    A->>A: 눈만 보이는 집중 화면 실행
    A-->>U: 10분 단위 남은 시간 잠깐 표시
    A-->>U: 중요 연락 또는 손 접근 경고
    A->>R: 정상 집중 완료 시 SESSION_END 명령
    R->>R: 스마트폰 잠금 해제
    A-->>U: 세션 리포트 제공
```

---

## 15. 슬로건 제안

> **집중할 땐 함께, 쉴 땐 자유롭게.**

또는

> **중요한 연결은 지키고, 불필요한 연결은 잠시 안녕.**

---

## 16. 최종 정리

월이는 스마트폰을 완전히 없애는 제품이 아니라 스마트폰의 기능을 집중에 유리한 방향으로 재구성하는 제품이다. 스마트폰은 화면, 센서, 마이크, 스피커, 알림, 데이터 처리를 담당하고 로봇은 거치, 잠금, 물리적 존재감과 캐릭터 경험을 담당한다.

이 구조를 적용하면 불필요한 하드웨어를 줄이면서도 개발 비용과 제작 난도를 낮출 수 있다. 동시에 사용자는 월이의 눈과 음성을 통해 단순한 타이머보다 친근하고 지속적인 집중 경험을 얻을 수 있다.

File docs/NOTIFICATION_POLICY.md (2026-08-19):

# WOLI 집중 알림 판단 기준

월이는 모든 메신저 알림을 읽어주는 앱이 아니라, 집중 중에도 놓치면 안 되는 연락만 남기는 디지털 디톡스 보조 앱입니다.

## 기본 원칙

1. 일반 카카오톡, 문자, DM은 기본적으로 음성 안내하지 않습니다.
2. 중요 연락처에서 온 알림은 음성 안내합니다.
3. 중요 연락처 알림에 긴급 표현이 있으면 긴급 알림으로 올립니다.
4. 알람, 일정, 리마인더는 중요한 시간성 알림으로 안내합니다.
5. 광고, 쿠폰, 좋아요, 댓글, 추천, 묶음 요약, 음악 재생 중, 백그라운드 상태 알림은 안내하지 않습니다.
6. 시연이 필요할 때만 `시연` 모드로 답장 가능한 테스트 메시지를 안내합니다.

## 정책 모드

| 모드 | 목적 | 안내 대상 |
|---|---|---|
| 집중 우선 | 실제 집중 사용 | 전화, 중요 연락처, 알람/일정 |
| 균형 | 기본값, 공모전 시연과 실사용 균형 | 전화, 중요 연락처, 긴급 표현, 허용 앱 |
| 시연 | 발표 중 답장 흐름 확인 | 균형 모드 + 답장 가능한 테스트 메시지 |

기본값은 `균형`입니다. 일반 메신저는 이 모드에서도 바로 안내되지 않고, 중요 연락처, 긴급 표현, 사용자가 허용한 앱 조건 중 하나를 만족해야 합니다.

## 판단 순서

| 순서 | 조건 | 결과 |
|---|---|---|
| 1 | 전화 알림 | 긴급 |
| 2 | 사용자가 차단한 앱 | 제외 |
| 3 | 음악 재생, 다운로드, 포그라운드 서비스 등 상태 유지 알림 | 제외 |
| 4 | 묶음 요약 또는 단체 대화 알림 | 제외 |
| 5 | 광고, 쿠폰, 할인, 혜택성 알림 | 제외 |
| 6 | 좋아요, 댓글, 팔로우, 추천 등 소셜 반응 알림 | 제외 |
| 7 | 중요 연락처 + 긴급 표현 | 긴급 |
| 8 | 중요 연락처 | 중요 |
| 9 | 알람, 일정, 리마인더 | 중요 |
| 10 | 균형/시연 모드 + 긴급 표현 + 1:1 메신저 | 긴급 |
| 11 | 균형/시연 모드 + 사용자가 허용한 앱의 1:1 메시지 | 중요 |
| 12 | 시연 모드 + 답장 가능한 1:1 테스트 메시지 | 중요 |
| 13 | 일반 카톡, 문자, DM | 제외 |
| 14 | 그 외 알림 | 제외 |

## 키워드 기준

### 긴급 표현

- 긴급
- 급해
- 급한
- 응급
- 위급
- 사고
- 병원
- 119
- 경찰
- 지금 전화
- 전화해
- 빨리
- asap
- emergency
- urgent
- help

### 차단 표현

- 광고
- 쿠폰
- 할인
- 특가
- 혜택
- 적립
- 이벤트
- 무료배송
- 좋아요
- 댓글
- 팔로우
- 추천 게시물
- sale
- coupon
- discount

## 시연 권장 설정

1. 설정 > 중요 연락처에서 테스트 연락처를 등록합니다.
2. 설정 > 집중 알림 기준에서 `균형` 모드를 선택합니다.
3. 카카오톡 또는 문자 메시지는 기본적으로 제외된다고 설명합니다.
4. 중요 연락처에서 메시지를 보내 `중요 연락처` 판단 기준이 표시되는지 확인합니다.
5. 같은 연락처가 `긴급이야 지금 전화해줘` 같은 메시지를 보내면 긴급 알림으로 올라가는지 확인합니다.
6. 답장 기능까지 보여줘야 하면 `시연` 모드로 바꾸고 테스트 메시지를 보냅니다.

## 검증 매트릭스

| 입력 예시 | 기대 결과 |
|---|---|
| 어머니 카톡 `도착하면 연락줘` | 중요 |
| 어머니 카톡 `긴급이야 지금 전화해줘` | 긴급 |
| 친구 카톡 `ㅋㅋ 뭐해` | 제외 |
| 단체방 `새 메시지 12개` | 제외 |
| 문자 `[광고] 쿠폰 할인` | 제외 |
| 캘린더 `10분 뒤 회의` | 중요 |
| 음악 앱 `재생 중` | 제외 |
| 인스타그램 `좋아요를 눌렀습니다` | 제외 |
| 허용 앱 1:1 메시지 | 중요 |
| 시연 모드 답장 가능 메시지 | 중요 |

## 한계

- 앱마다 알림 제목, 본문, 단체방 여부를 Android에 제공하는 방식이 다릅니다.
- 일부 메신저는 단체방 여부를 명확히 제공하지 않을 수 있습니다.
- 실제 답장 가능 여부는 Android `RemoteInput` 제공 여부에 따라 달라집니다.
- 실기기에서 카카오톡, 문자, Telegram, WhatsApp을 각각 검증해야 최종 시연 안정성을 판단할 수 있습니다.

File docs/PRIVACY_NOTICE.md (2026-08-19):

# WOLI 개인정보 및 권한 안내

월이는 집중 중 중요한 연락만 안내하고, 사용자가 음성으로 답장 여부를 선택할 수 있도록 돕는 Android 앱입니다.

## 수집하거나 접근하는 정보

월이는 다음 정보를 단말 안에서만 사용합니다.

- 중요 연락처 이름과 전화번호
- 알림 제목, 앱 이름, 간단한 본문 요약
- 알림 판단 모드, 허용 앱, 긴급 키워드 등 집중 알림 기준 설정
- 답장 전송 성공/실패 이력
- 전화 수신 상태와 발신자 정보
- BLE 기기 연결 상태와 하드웨어 센서 상태

현재 저장소 기준으로 외부 서버, 클라우드 DB, 원격 분석 SDK로 데이터를 전송하지 않습니다.

## 권한 사용 목적

| 권한 | 목적 |
|---|---|
| 알림 접근 | 집중 중 중요 알림 감지 및 TTS 안내 |
| 알림 표시 | 포그라운드 서비스 실행 상태 표시 |
| 연락처 | 저장된 중요 연락처와 알림/전화 발신자 매칭 |
| 전화 상태 | 수신 전화 감지 |
| 통화 기록 | 가능한 기기에서 발신자 번호 식별 |
| 전화 제어 | 가능한 기기에서 받기/거절 명령 시도 |
| 마이크 | 음성 명령 및 답장 초안 입력 |
| Bluetooth | ESP32 월이 기기 검색, 연결, 잠금 명령 |
| 카메라 | 향후 시선/상태 인식 확장 대비 |

## 저장 위치와 삭제

- 중요 연락처, 집중 세션, 집중 알림 기준, 답장 이력은 앱 로컬 저장소에 저장됩니다.
- 앱을 삭제하면 로컬 데이터도 함께 삭제됩니다.
- 시연 전에는 개인 계정 대신 테스트 계정과 발표용 연락처를 사용하는 것을 권장합니다.

## 한계

- Android 제조사, OS 버전, 메시지 앱 정책에 따라 답장/전화 제어가 실패할 수 있습니다.
- 알림 접근 권한이 꺼져 있으면 월이가 메시지 내용을 알 수 없습니다.
- 배터리 최적화가 강한 기기에서는 백그라운드 TTS나 BLE 유지가 중단될 수 있습니다.

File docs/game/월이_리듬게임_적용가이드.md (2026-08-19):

# 월이 · 집중 모드 중도 해제 리듬게임 — 적용 가이드

## 무엇을 / 왜

기획안 **4.5 중도 해제 방지 미션**의 "행동 마찰 장치"를 정통 리듬게임으로 구현했습니다.
흐름은 그대로입니다: 집중 시간을 못 채운 채 종료를 시도 → `QuitConfirmScreen`("정말 종료할까요?") →
"미션 시작" → **리듬게임** → 통과해야만 물리 잠금이 풀립니다.

기존 화면은 "정해진 순서대로 레인 탭하기"라 리듬게임이 아니었습니다. 이번에 **노트가 레인을 따라
떨어지고 판정선에서 타이밍에 맞춰 탭 → Perfect/Good/Miss 판정**하는 방식으로 교체했고, 난이도는
기획 의도(충동적 해제를 한 번 더 생각하게 만드는 정도)에 맞춰 **적당한 마찰(약 20~30초, 집중해야 통과)**로 잡았습니다.

## 변경 요약 (4개 파일)

| 파일 | 상태 | 내용 |
|---|---|---|
| `focus/WoliRhythmGame.kt` | 신규 | 순수 Kotlin 게임 엔진 — 차트 생성·판정·점수·통과 규칙. 단위 테스트 대상. |
| `ui/screens/RhythmMissionScreen.kt` | 신규 | 새 Compose 화면 — 프레임 루프(withFrameNanos)·노트 렌더·레인 입력·결과 오버레이. |
| `ui/screens/FocusScreens.kt` | 수정 | 구버전 `RhythmMissionScreen` + `RhythmShellVisual` 제거(중복 선언 방지). |
| `test/.../WoliRhythmGameTest.kt` | 신규 | 엔진 단위 테스트 12개. |

> **MainActivity / 네비게이션은 손댈 필요 없습니다.** 새 화면의 시그니처가 기존과 동일
> (`RhythmMissionScreen(onSuccess, onCancel)`)하고, 같은 패키지(`com.woli.app.ui.screens`)에 있어
> `MainActivity`의 import와 `Routes.RHYTHM_MISSION` 연결이 그대로 유지됩니다.

## 적용 방법 (셋 중 하나)

### A. git 패치 — 팀 협업에 추천
```bash
cd Project-WallE
git apply --stat  rhythm-game.patch   # 무엇이 바뀌는지 미리보기
git apply --check rhythm-game.patch   # 충돌 여부 확인
git apply         rhythm-game.patch   # 적용
```
`--check`에서 충돌이 나면(= 로컬 `FocusScreens.kt`가 GitHub `main`과 다르면) 아래 B 또는 C를 쓰세요.

### B. zip 덮어쓰기 — 로컬이 `main`과 동기화된 경우
```bash
unzip -o walle-rhythm-game-files.zip -d Project-WallE
```
zip 안의 4개 파일이 저장소의 제자리에 들어갑니다.

### C. 수동 — 로컬이 많이 달라졌을 때 가장 안전
1. 신규 파일 3개를 그대로 추가: `WoliRhythmGame.kt`, `RhythmMissionScreen.kt`, `WoliRhythmGameTest.kt`.
2. `FocusScreens.kt`에서 **아래 두 함수만 통째로 삭제**:
   - `@Composable fun RhythmMissionScreen(onSuccess: () -> Unit, onCancel: () -> Unit) { ... }`
   - `@Composable private fun RhythmShellVisual(targetLane: Int) { ... }`

   두 함수를 안 지우면 같은 이름이 중복 선언되어 컴파일 에러가 납니다. (`MainActivity`는 그대로 두세요.)

## 빌드 & 테스트
```bash
cd android
./gradlew.bat :app:assembleDebug
./gradlew.bat :app:testDebugUnitTest    # 새 리듬 엔진 테스트 포함
```
집중 화면들은 가로(landscape) 라우트입니다(거치 시 가로). 에뮬레이터에서 종료 → 미션 시작으로 진입해 확인하세요.

## 동작 흐름 / 통합 지점

- **진입**: `QuitConfirmScreen`의 "미션 시작" → `Routes.RHYTHM_MISSION` → `RhythmMissionScreen`.
- **성공**(목표 성공 수 도달) 시 기존과 동일하게 호출:
  `recordMissionAttempt(success = true)` → `WoliFocusSessionController.complete(MissionUnlocked)` →
  `WoliDeviceCenter.setLocked(false)` → `WoliFocusGuardService.stop(context)` → `onSuccess()`(홈으로).
- **실패**(허용 실패치 초과 또는 노트 소진 후 목표 미달) 시:
  `recordMissionAttempt(success = false)` 후 "다시 시도 / 집중 계속하기" 오버레이 표시.
- 세션 리포트의 **미션 성공/시도 카운트**에 그대로 집계됩니다(`missionSuccessCount / missionAttemptCount`).

## 난이도 조절 (한 줄이면 끝)

`RhythmMissionScreen.kt` 상단:
```kotlin
val config = remember { WoliRhythmConfig.Moderate }   // Light / Moderate / Intense
```
또는 직접 값을 지정:
```kotlin
val config = remember {
    WoliRhythmConfig(
        laneCount = 3,        // 레인 수 (Intense는 4)
        bpm = 95,             // 템포
        totalNotes = 28,      // 총 노트 수
        approachMs = 1500,    // 노트가 떨어지는 시간 (작을수록 빠르고 어려움)
        perfectWindowMs = 80, // Perfect 판정 폭 (ms)
        goodWindowMs = 150,   // Good 판정 폭 (ms)
        requiredHits = 18,    // 통과에 필요한 성공(Perfect+Good) 수
        maxMisfires = 10,     // 놓침+헛침 허용치 (넘으면 실패 → 재시도)
    )
}
```
프리셋 요약 — **Light**(몇 초, 심리적 장벽만) · **Moderate**(기본, 20~30초) · **Intense**(4레인·빠름, 발표 임팩트용).

> 확장 아이디어: 집중 시간(`session.config.durationMinutes`)이 길수록 더 어려운 프리셋을 고르면,
> "오래 집중했을수록 깨기 아깝게" 만드는 심리 설계를 넣을 수 있습니다.

## 검증 완료

- 엔진 단위 테스트 12개를 kotlinc 2.0.21로 **컴파일·실행 → 12/12 통과**.
  (판정 윈도우 Perfect/Good/Miss, 점수·콤보, 통과/실패 임계, 차트 결정성, 같은 노트 중복 탭 방지, 헛침 페널티 등)
- Compose 화면은 저장소의 기존 컴포넌트/테마(`WoliPrimaryButton`, `WoliCyan` 등)와 패턴에 맞춰 작성했습니다.
  최종 컴파일 확인은 Android Studio 빌드에서 하시면 됩니다(엔진과 UI가 분리돼 있어 로직은 이미 검증됨).

## 다음에 얹으면 좋은 것 (선택)

- **사운드**: `res/raw`에 비트 파일을 넣고 SoundPool/ToneGenerator로 박자 틱·타격음. (지금은 무음 + 성공 타격 시 햅틱 진동)
- **롱노트 / 동시치기 / 난이도 상승 곡선** — 엔진 차트 생성부만 확장하면 됩니다.
- 해제 시도 패턴을 세션 리포트 통계로 연결(며칠째 몇 번 시도 등).

## Claude Code로 이어서 작업 (로컬)

Android Studio를 쓰신다면 프로젝트 폴더에서 그대로 Claude Code를 붙일 수 있습니다:
```bash
cd Project-WallE/android
claude                     # 이 파일들 기준으로 계속 확장/디버그
```
팀 협업이라면 브랜치를 파서 커밋하는 흐름을 추천합니다:
```bash
git checkout -b feat/rhythm-game
git apply rhythm-game.patch
git add -A && git commit -m "feat(focus): 중도 해제 방지 리듬게임 구현"
git push -u origin feat/rhythm-game     # PR 올리기
```

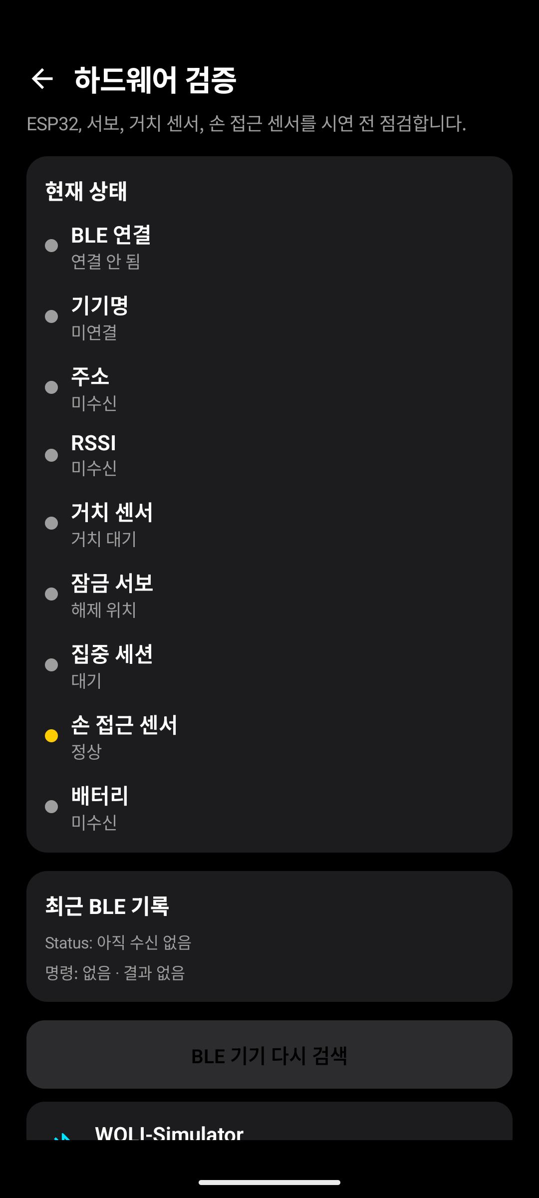
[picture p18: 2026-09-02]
docs/screenshots-capture/hardware_diagnostics.png

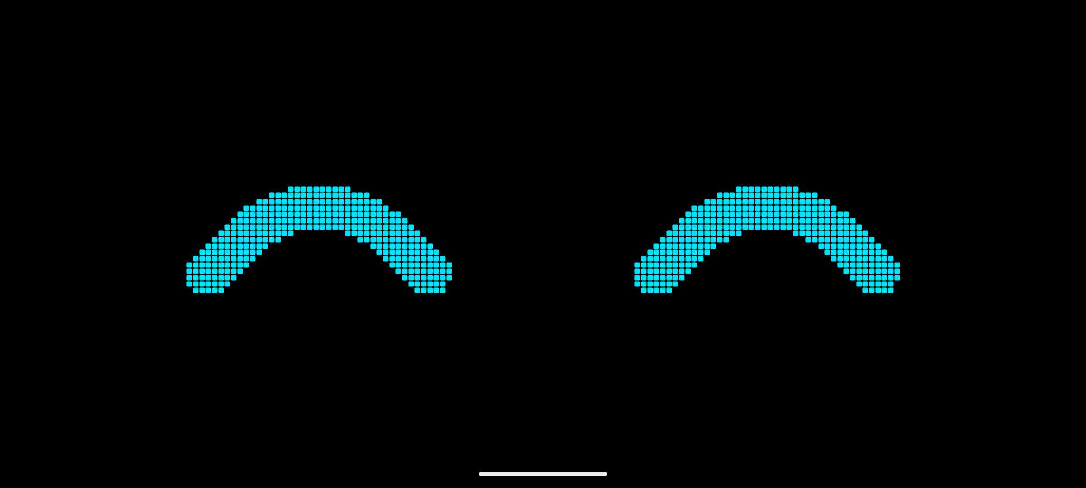
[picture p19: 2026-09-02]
docs/screenshots-capture/session_report.png

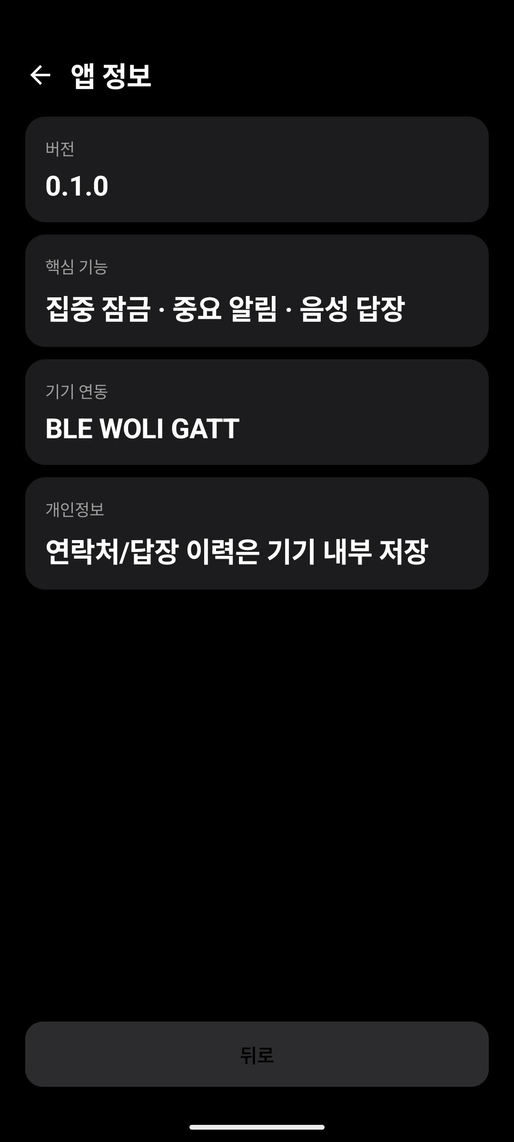
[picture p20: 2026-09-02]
docs/screenshots-capture/app_info.png

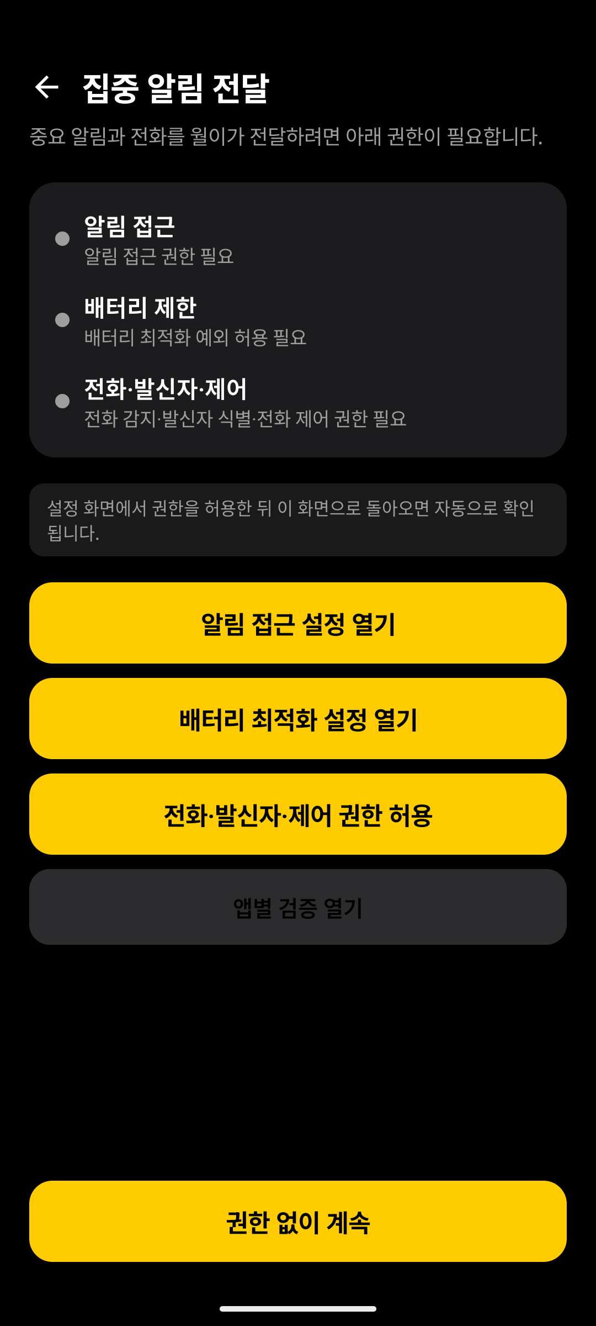
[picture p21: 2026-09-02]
docs/screenshots-capture/focus_notification_permission.png

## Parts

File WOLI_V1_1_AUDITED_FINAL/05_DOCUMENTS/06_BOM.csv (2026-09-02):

Category | Item | Qty | Status
Drive | N20 geared motor | 2 | Envelope confirmed
Drive | Wheel Ø43×17.5 | 2 | Confirmed
Drive | N20 metal bracket 25×8.5×11.5 | 2 | Confirmed envelope / slots used
Support | Ball caster 22×17×15 | 1 | Confirmed envelope / clip-fit validation
Power | KLIFE PD-Q2 10000mAh 68×143×11 | 1 | Confirmed / approx205g
Control | Main PCB 50×70×approx15 | 1 | Confirmed envelope
Motor driver | TB6612FNG HW-166 26×26 | 1 | Confirmed plan size
Power I/O | USB-C female breakout approx12×15 | 1 | Approx plan size / connector approx4.2
Actuator | MG90S | 1 | Mount based on supplied product image
Sensor | Limit switch | 1 | Envelope based on supplied product image
Sensor | VL53L0X | 1 | Envelope based on supplied product image
Phone | Commercial holder/socket | 1 | Ø16 fit physical validation

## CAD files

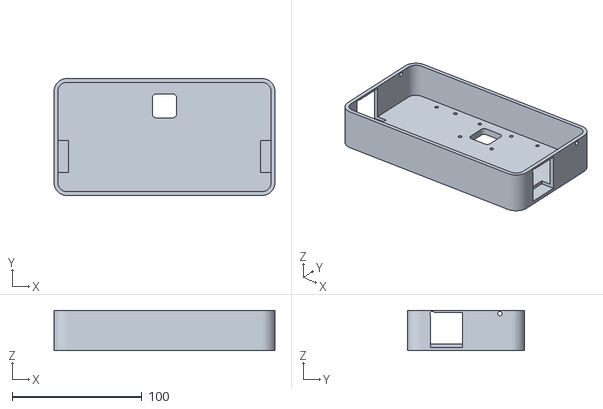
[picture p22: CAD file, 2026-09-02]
WOLI_V1_1_AUDITED_FINAL/02_STL_RELEASE/01_main_chassis.stl
170.0 x 90.0 x 31.0

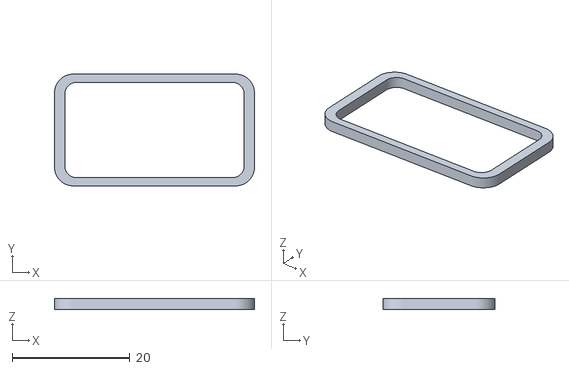
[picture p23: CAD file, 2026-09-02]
WOLI_V1_1_AUDITED_FINAL/02_STL_RELEASE/17_tof_front_bezel.stl
34.0 x 19.0 x 1.80

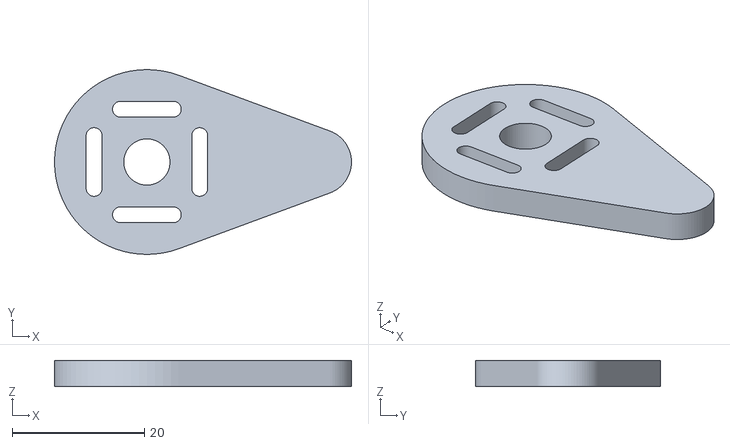
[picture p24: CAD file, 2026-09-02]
WOLI_V1_1_AUDITED_FINAL/03_STL_FIT_TEST/23_lock_arm_reach_26mm.stl
45.0 x 28.0 x 4.00

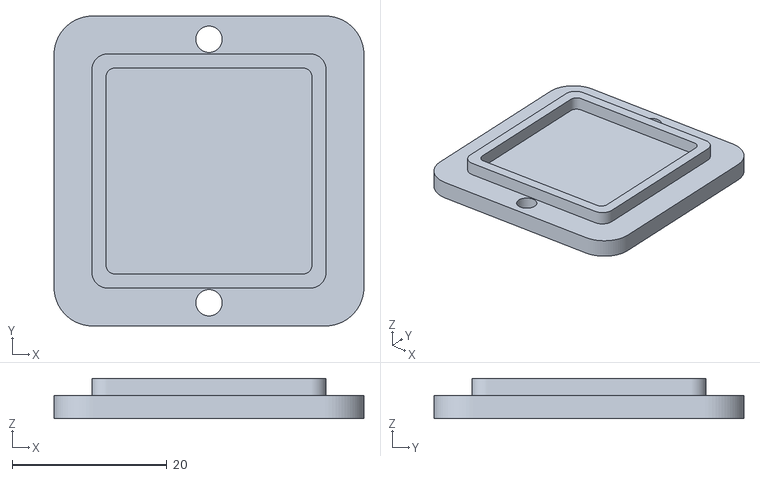
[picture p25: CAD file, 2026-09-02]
WOLI_V1_1_AUDITED_FINAL/02_STL_RELEASE/15_tb6612fng_tray.stl
40.0 x 40.0 x 5.20

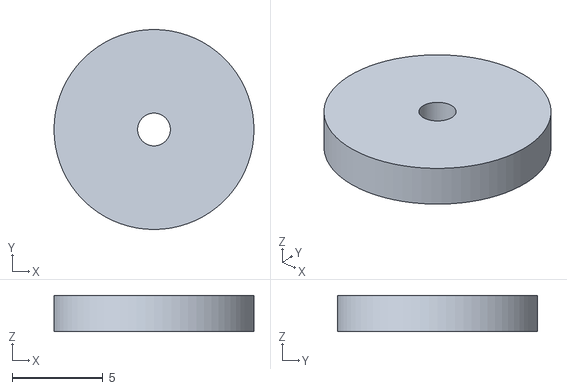
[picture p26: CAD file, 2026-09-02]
WOLI_V1_1_AUDITED_FINAL/03_STL_FIT_TEST/24_lock_contact_pad.stl
11.0 x 11.0 x 2.00

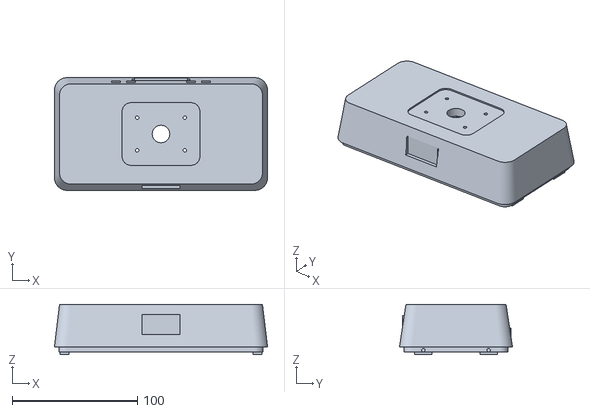
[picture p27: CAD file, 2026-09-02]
WOLI_V1_1_AUDITED_FINAL/02_STL_RELEASE/03_top_cover.stl
170.0 x 90.0 x 40.0

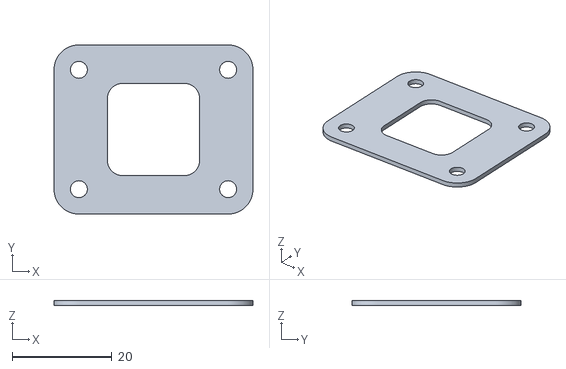
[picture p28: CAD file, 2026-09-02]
WOLI_V1_1_AUDITED_FINAL/03_STL_FIT_TEST/09C_caster_shim_2mm.stl
40.0 x 34.0 x 1.00

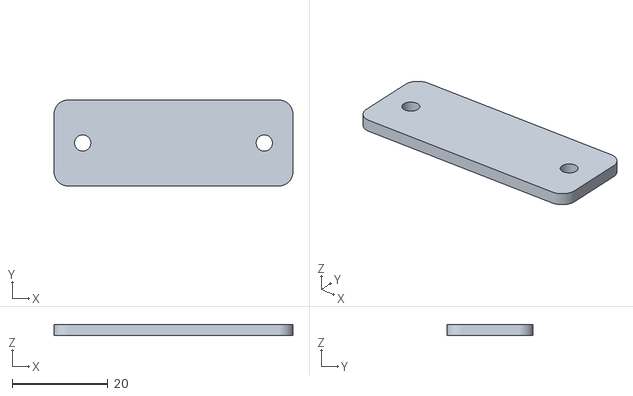
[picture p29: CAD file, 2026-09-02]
WOLI_V1_1_AUDITED_FINAL/02_STL_RELEASE/13_rear_service_hatch.stl
50.0 x 18.0 x 2.40

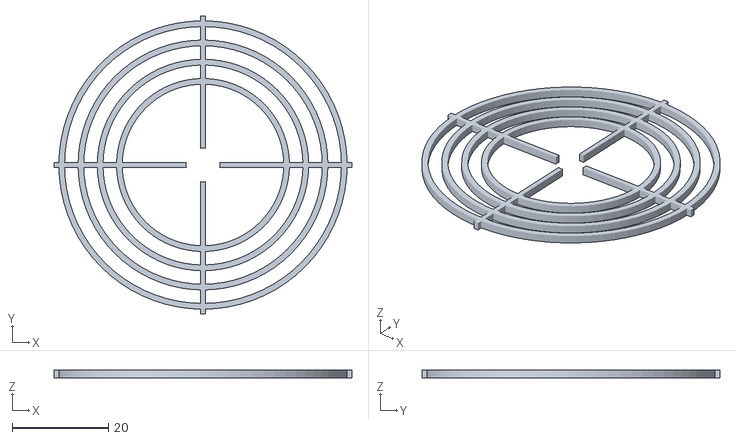
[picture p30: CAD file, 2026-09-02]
WOLI_V1_1_AUDITED_FINAL/03_STL_FIT_TEST/25_servo_lock_datum_jig.stl
62.0 x 62.0 x 1.60

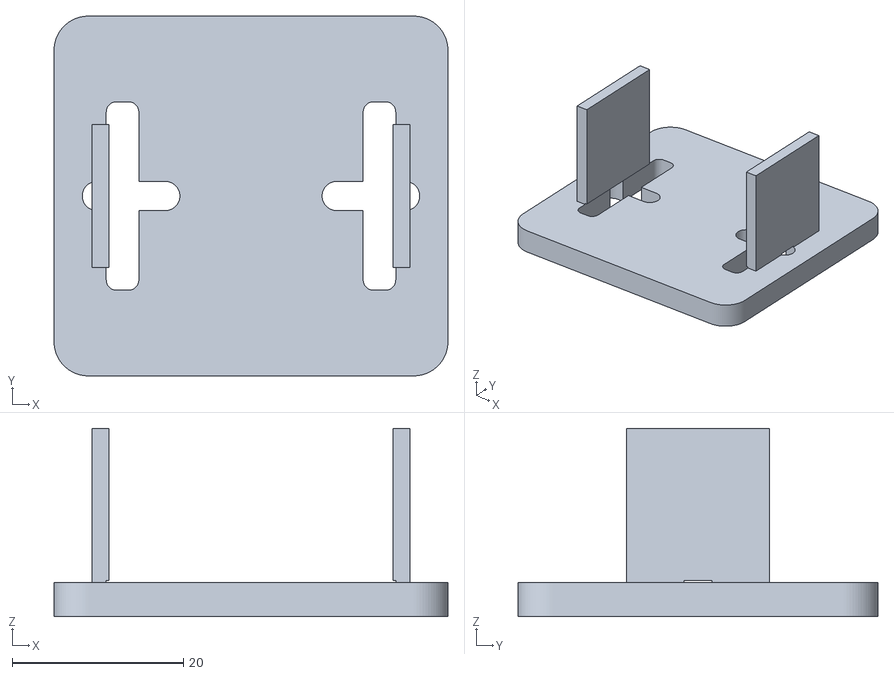
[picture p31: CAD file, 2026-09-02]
WOLI_V1_1_AUDITED_FINAL/02_STL_RELEASE/05_servo_mount.stl
46.0 x 42.0 x 22.0

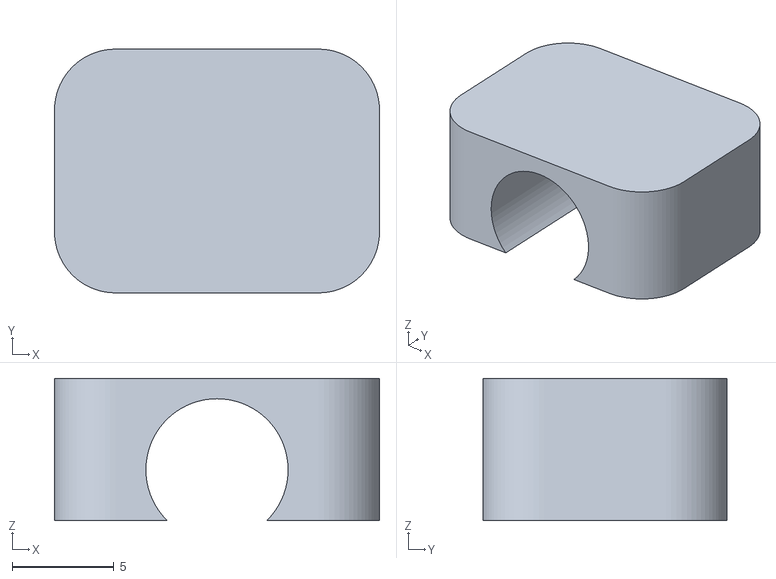
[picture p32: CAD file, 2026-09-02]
WOLI_V1_1_AUDITED_FINAL/02_STL_RELEASE/10_cable_clip.stl
16.0 x 12.0 x 7.00

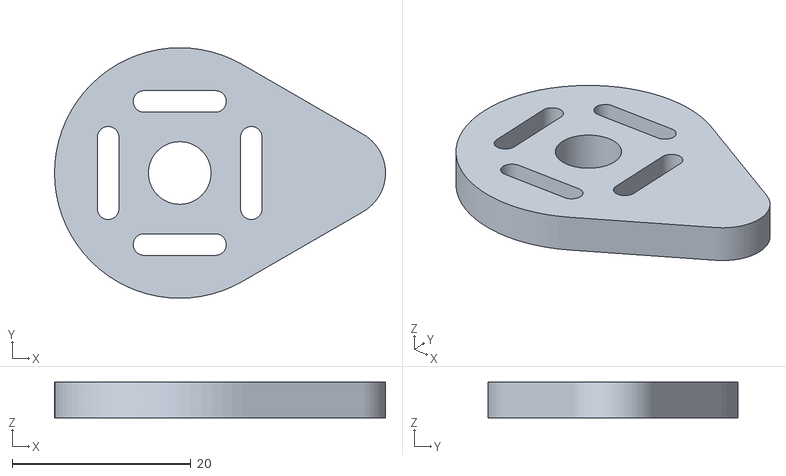
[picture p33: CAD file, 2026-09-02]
WOLI_V1_1_AUDITED_FINAL/03_STL_FIT_TEST/23_lock_arm_reach_18mm.stl
37.0 x 28.0 x 4.00

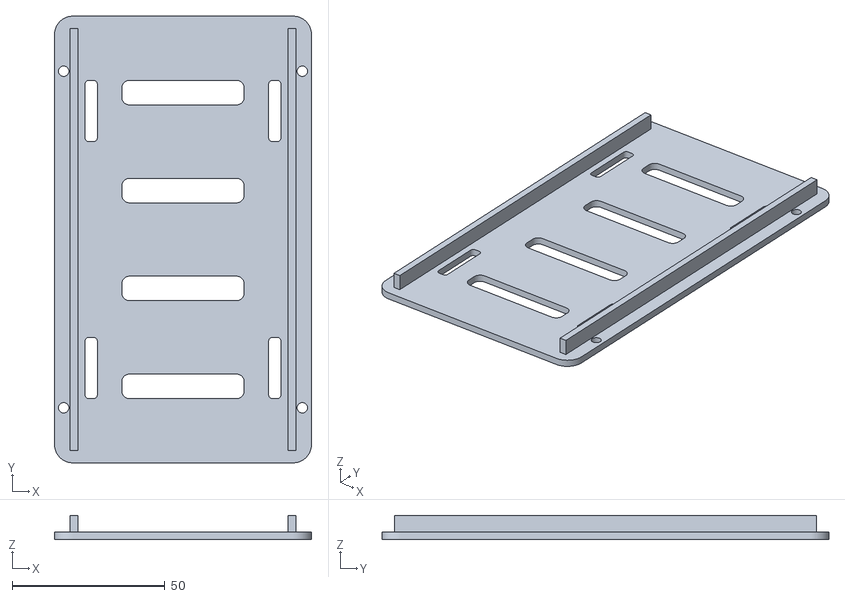
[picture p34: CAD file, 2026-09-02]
WOLI_V1_1_AUDITED_FINAL/02_STL_RELEASE/19B_klife_pd_q2_battery_tray.stl
84.0 x 146.0 x 7.90

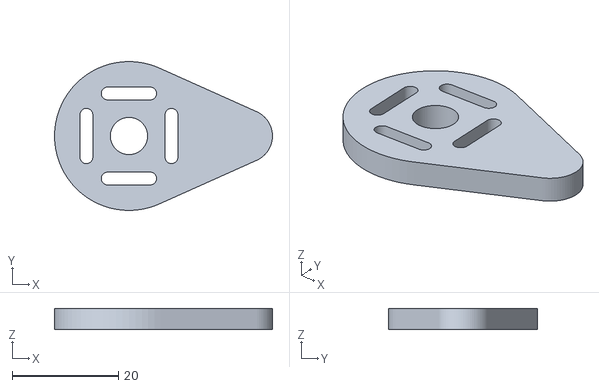
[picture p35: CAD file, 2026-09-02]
WOLI_V1_1_AUDITED_FINAL/03_STL_FIT_TEST/23_lock_arm_reach_22mm.stl
41.0 x 28.0 x 4.00

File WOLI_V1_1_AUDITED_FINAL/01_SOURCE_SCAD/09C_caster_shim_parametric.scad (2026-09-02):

include <woli_lib.scad>;
shim_h = is_undef(SHIM_H) ? 1 : SHIM_H;

difference(){
    rplate(40,34,shim_h,5);

    translate([0,0,-0.1])
        rplate(caster_floor_open,caster_floor_open,shim_h+0.3,3);

    for(x=[-caster_mount_x,caster_mount_x])
        for(y=[-caster_mount_y,caster_mount_y])
            translate([x,y,-0.1])
                cylinder(h=shim_h+0.3,d=m3_clear);
}

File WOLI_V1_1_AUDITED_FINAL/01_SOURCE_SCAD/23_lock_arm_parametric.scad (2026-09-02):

include <woli_lib.scad>;

// ============================================================
// 23 PARAMETRIC LOCK ARM MODULE V0.7
// Call: lock_arm_custom(reach_mm)
// ============================================================

module lock_arm_custom(reach_mm=22){
    difference(){
        linear_extrude(height=lock_arm_t)
            hull(){
                circle(d=lock_plate_d);
                translate([reach_mm,0]) circle(d=lock_tip_d);
            }

        translate([0,0,-0.1])
            cylinder(h=lock_arm_t+0.3,d=horn_center_clear_d);

        for(a=[0,90,180,270])
            rotate([0,0,a])
                translate([horn_slot_radius,0,-0.1])
                    rotate([0,0,90])
                        slot3d(horn_slot_len,horn_slot_d,lock_arm_t+0.3);
    }
}

// Default preview when opening this file directly.
lock_arm_custom(lock_reach);

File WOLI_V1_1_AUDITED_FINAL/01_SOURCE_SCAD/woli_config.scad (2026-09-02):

// ============================================================
// WOLI V1.1 AUDITED FINAL — MASTER PARAMETERS
// Units: mm
// ============================================================

$fn = 72;

// ---------- GLOBAL ----------
fit_clearance = 0.40;
wall = 3.0;
floor_t = 5.0;
cover_t = 2.8;
shell_r = 10.0;

m3_clear = 3.4;
m3_pilot_d = 2.8;
m3_pilot_depth = 4.2;

tie_slot_w = 3.8;
tie_slot_l = 18;

// ---------- BODY ----------
body_w = 170;
body_l = 90;
chassis_h = 31;
top_h = 34;

top_upper_w = 162;
top_upper_l = 80;
top_upper_r = 9;

// ---------- N20 DRIVE ----------
wheel_d = 43;
wheel_w = 17.5;

n20_x = 12;
n20_y = 33;
n20_z = 10;

n20_bracket_x = 25;
n20_bracket_y = 8.5;
n20_bracket_z = 11.5;
n20_bracket_hole_cc = 17;      // approx; slots absorb error

wheel_axis_ground_z = wheel_d/2; // reference only; actual chassis ground plane requires hardware check
wheel_opening_l = 25;            // side wheel cutout depth (Y), mm
motor_y = -body_l/2 + body_l/3;  // wheel center: 1/3 body depth in from front (-Y)
motor_slot_len = 8;
motor_bracket_zone_x = body_w/2 - 18;

// ---------- BALL CASTER ----------
caster_w = 22;
caster_l = 17;
caster_h = 15;
caster_ball_d_visual_ref = 11.5; // photo-only reference; not used for fit
caster_dock_y = body_l/2 - 21;

caster_body_clear = 0.7;
caster_retainer_t = 3.0;
caster_retainer_screw_cc = 27;

caster_mount_x = 15;
caster_mount_y = 12;
caster_floor_open = 18.5;

// ---------- MAIN PCB ----------
pcb_w = 50;
pcb_l = 70;
pcb_stack_h = 15;

pcb_tray_w = 56;
pcb_tray_l = 76;
pcb_mount_cc_x = 44;
pcb_mount_cc_y = 64;

// ---------- MG90S ----------
servo_a = 32.4;
servo_b = 32.5;
servo_c = 12;
servo_fit = 0.7;

// ---------- LIMIT SWITCH ----------
limit_w = 21;
limit_l = 23;
limit_h = 6;

// ---------- VL53L0X ----------
tof_w = 10.7;
tof_l = 25;
tof_h = 11.5;
tof_rail_clear = 0.7;

tof_bezel_w = 34;
tof_bezel_h = 19;

// ---------- PHONE HOLDER / NECK ----------
phone_ball_d = 18.0;            // physical socket fit still required
neck_h = 30;
neck_base_w = 54;
neck_base_l = 42;
neck_base_h = 5;
neck_hole_x = 38;
neck_hole_y = 26;

neck_recess_w = 62;
neck_recess_l = 50;
neck_recess_d = 1.2;

neck_pilot_d = 2.8;
neck_pilot_depth = 7.0;

// reference phone clearance envelope only
phone_ref_w = 165;
phone_ref_h = 82;
phone_ref_t = 12;

// ---------- KLIFE PD-Q2 BATTERY ----------
battery_w = 68;
battery_l = 143;
battery_h = 11;
battery_mass_g = 205;

battery_fit_clear = 0.8;
battery_tray_w = 84;
battery_tray_l = 146;
battery_tray_t = 2.4;
battery_rail_t = 2.5;
battery_rail_h = 5.5;
battery_center_y = -18;

battery_tray_mount_x = 39;
battery_tray_mount_y = 55;

// ---------- UPPER ELECTRONICS DECK ----------
bridge_w = 122;
bridge_l = 94;
bridge_t = 3.0;
bridge_leg_h = 20;
bridge_leg_x = 56;
bridge_leg_y = 36;

module_boss_h = 4.5;
module_boss_d = 8.0;
module_pilot_d = 2.8;

pcb_deck_cx = -25;
pcb_deck_cy = 0;

tb_deck_cx = 34;
tb_deck_cy = 17;

usbc_deck_cx = 36;
usbc_deck_cy = -24;

// ---------- TB6612FNG HW-166 ----------
tb6612_w = 26;
tb6612_l = 26;
tb6612_clear = 0.6;

// total installed height is intentionally not hard-coded

// ---------- USB-C BREAKOUT ----------
usbc_board_w = 12;
usbc_board_l = 15;
usbc_connector_h = 4.2;
usbc_clear = 0.6;

// ---------- TOP COVER INTERFACE ----------
cover_skirt_depth = 4.0;
cover_skirt_clear = 0.8;
cover_skirt_t = 2.5;

cover_side_screw_y = 55 * body_l / 190;
cover_side_screw_z = -2.5;

rear_service_w = 42;
rear_service_h = 14;
rear_hatch_screw_x = 19;
rear_hatch_center_z = 10;

// ---------- CABLE MANAGEMENT ----------
cable_bridge_w = 24;
cable_bridge_l = 14;
cable_bridge_h = 8;
cable_bridge_channel = 8;

// ---------- SERVO LOCK FRAMEWORK ----------
lock_angle_deg = 90;
unlock_angle_deg = 10;

lock_plate_d = 28;
lock_arm_w = 10;
lock_arm_t = 4.0;
lock_reach = 22;
lock_tip_d = 10;

horn_center_clear_d = 7.0;
horn_slot_d = 2.4;              // physical stock-horn check required
horn_slot_len = 8.0;
horn_slot_radius = 8.0;

lock_pad_t = 2.0;
lock_pad_d = 11.0;

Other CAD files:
WOLI_V1_1_AUDITED_FINAL/03_STL_FIT_TEST/13B_rear_service_hatch_usbc_TEST.stl
WOLI_V1_1_AUDITED_FINAL/02_STL_RELEASE/21_upper_electronics_bridge.stl
WOLI_V1_1_AUDITED_FINAL/03_STL_FIT_TEST/23_lock_arm_reach_30mm.stl
WOLI_V1_1_AUDITED_FINAL/02_STL_RELEASE/09B_caster_tab_retainer.stl
WOLI_V1_1_AUDITED_FINAL/01_SOURCE_SCAD/05_servo_mount.scad
WOLI_V1_1_AUDITED_FINAL/01_SOURCE_SCAD/01_main_chassis.scad
WOLI_V1_1_AUDITED_FINAL/01_SOURCE_SCAD/03_top_cover.scad
WOLI_V1_1_AUDITED_FINAL/01_SOURCE_SCAD/04_pcb_tray.scad
WOLI_V1_1_AUDITED_FINAL/01_SOURCE_SCAD/06_limit_switch_mount.scad
WOLI_V1_1_AUDITED_FINAL/01_SOURCE_SCAD/08_phone_neck_16mm.scad
WOLI_V1_1_AUDITED_FINAL/01_SOURCE_SCAD/09B_caster_tab_retainer.scad
WOLI_V1_1_AUDITED_FINAL/01_SOURCE_SCAD/09C_caster_shim_1mm.scad
WOLI_V1_1_AUDITED_FINAL/01_SOURCE_SCAD/09C_caster_shim_2mm.scad
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

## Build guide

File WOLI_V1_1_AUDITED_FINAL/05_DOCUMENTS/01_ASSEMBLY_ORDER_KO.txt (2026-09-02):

WOLI V1.1 권장 조립 순서
=========================

1. 01 Main Chassis
- 바닥면 DOWN, Open cavity UP으로 출력

2. N20 Motor + Metal Bracket + Ø43 Wheel ×2
- Motor bracket slot으로 위치 미세 보정
- Wheel이 body와 닿지 않는지 확인

3. 19B KLIFE Battery Tray
- M3×6 ×4 권장
- Chassis blind pilot에 저토크로 self-thread
- Battery 장착 후 strap/Velcro 고정

4. Ball Caster
- 09 Caster Cartridge
- 실제 22×17×15 caster
- 09B Tab Retainer
- Cartridge→Chassis: M3×8 ×4
- Retainer→Cartridge: M3×6 ×2
- 실제 캐스터에는 구멍을 뚫지 않음

5. 21S 20mm Electronics Standoff ×4

6. 21 Upper Electronics Deck
- Flat Deck
- M3×30 ×4를 Deck→Standoff→Chassis pilot 순으로 체결

7. 04 Main PCB Tray
- 전용 Deck boss
- M3×6 ×4

8. 15 TB6612FNG Tray
- 전용 Deck boss
- M3×6 ×2

9. 16 USB-C Holder
- 전용 Deck boss
- M3×6 ×2

10. MG90S / Limit Switch
- 05 Servo Mount / 06 Limit Mount
- 최종 Lock 접점은 실물 테스트 후 위치 고정

11. VL53L0X
- Top Cover 내부 front guide rail에 삽입
- 전면 single rectangular optical opening과 정렬

12. Top Cover
- 내부 locating skirt를 chassis 안쪽에 삽입
- Chassis 좌/우 측면 M3×10 ×4 체결

13. Phone Neck
- Ø16 Neck base를 Top Cover recess에 넣음
- M3×10 ×4
- reinforced blind pilot 사용

14. Rear Service Hatch
- 기본: 13 closed hatch
- USB 외부 노출 실험: 13B TEST hatch
- M3×6 ×2

15. Servo Lock
- Fit Test 폴더의 18 / 22 / 26 / 30mm arm으로 실제 holder 차단거리 확인
- Phone 자체를 누르지 않고 Holder release path만 차단

16. 전체 점검
- Wheel rotation
- Caster ground contact
- Battery restraint
- Deck clearance
- Top cover fit
- ToF optical path
- Phone sag
- Servo stall 없음
- Wire pinch 없음

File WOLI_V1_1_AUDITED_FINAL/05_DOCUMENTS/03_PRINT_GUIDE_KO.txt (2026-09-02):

WOLI V1.1 PRINT GUIDE
=====================

Material
- Black PLA

Recommended
- Nozzle 0.4mm
- Layer 0.20mm
- Exterior cover 0.16~0.20mm
- Walls 4
- Top/Bottom 5~6 layers
- General infill 25%
- Structural parts 30~40%

Minimum build area
- 약155×195mm 이상 권장

Orientation
01 Main Chassis
- Floor DOWN / cavity UP

03 Top Cover
- 180° 뒤집어서 exterior roof DOWN
- cavity UP
- internal front ToF guide에만 필요한 경우 제한적 support

21 Upper Electronics Deck
- Plate DOWN / mounting bosses UP

21S Standoff
- Vertical
- 4개 출력

19B Battery Tray
- Base DOWN

09 / 09B Caster parts
- Flat DOWN

08 Phone Neck
- Base DOWN
- Ball 주변 support 사용 권장

금지
- STL 전체 Scale 조정으로 공차 해결 금지
- SCAD parameter를 수정 후 STL 재생성

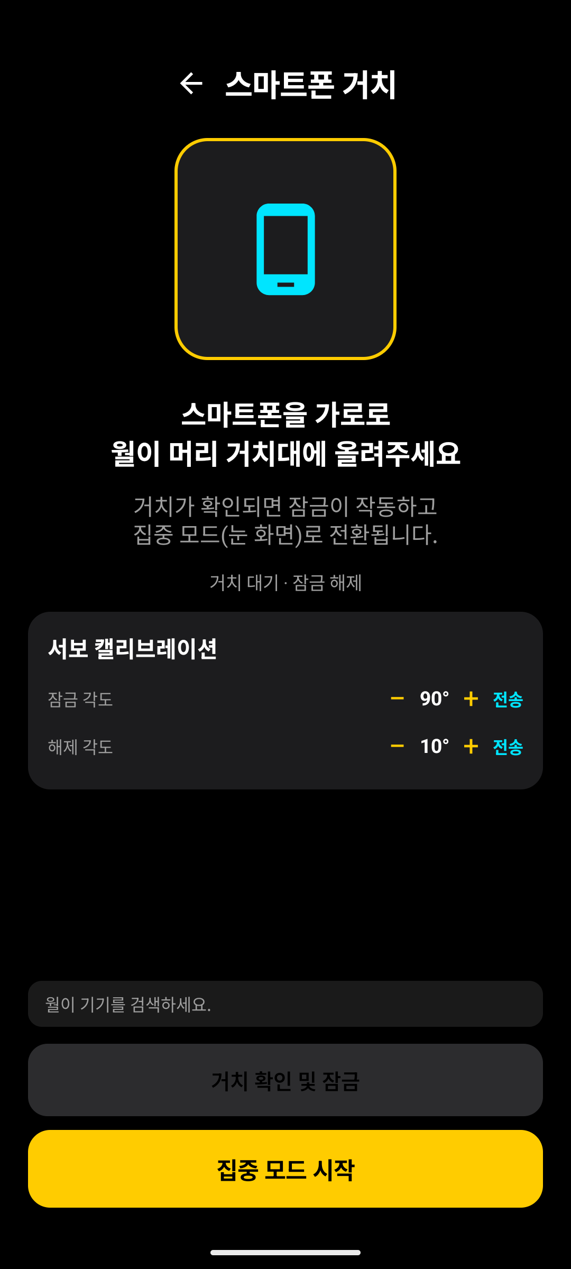
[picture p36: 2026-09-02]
docs/screenshots-capture/mount_guide.png

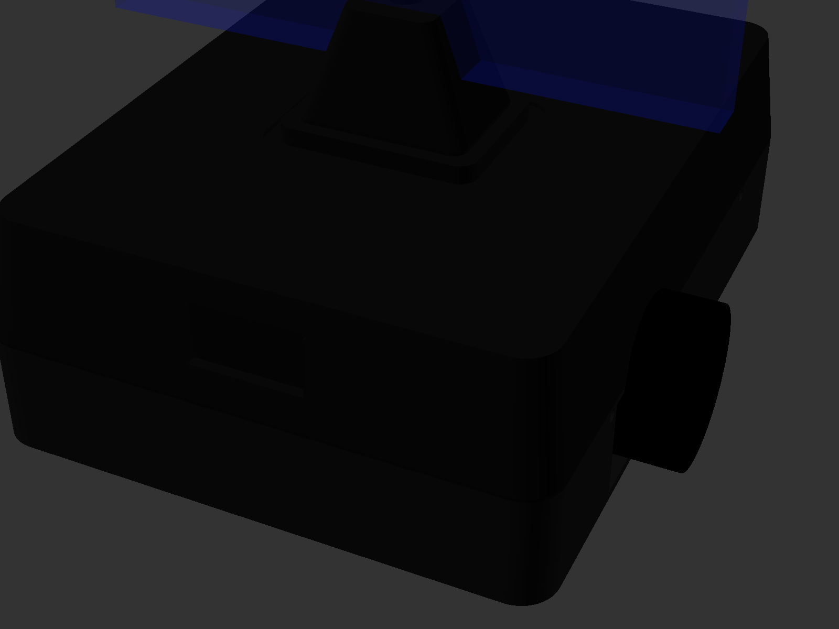
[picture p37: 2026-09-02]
WOLI_V1_1_AUDITED_FINAL/04_REFERENCE/90_release_assembly_render.png

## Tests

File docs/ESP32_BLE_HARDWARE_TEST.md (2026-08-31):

# WOLI ESP32 BLE 실기기 검증

이 문서는 ESP32-WROOM-32와 Android 앱의 BLE, 거치/손 접근 입력, 서보 잠금 상태를 실제 부품으로 확인하는 절차입니다. 실제 부품이 없으면 아래 결과를 검증 완료로 표시하지 말고 Android의 `WOLI-Simulator`를 별도 시연 경로로 사용합니다.

## 연결과 안전

| 용도 | ESP32 핀 | 기본 설정 |
|---|---:|---|
| 잠금 서보 신호 | GPIO 18 | `LOCK_SERVO_DEGREES=90`, `UNLOCK_SERVO_DEGREES=10` |
| 스마트폰 거치 스위치 | GPIO 19 | `INPUT_PULLUP`, active-low |
| 손 접근 디지털 입력 | GPIO 21 | `INPUT_PULLUP`, active-low |
| 배터리 ADC | 미사용 (`-1`) | 현재는 `battery=100` 보고 |

- 거치 스위치는 GPIO 19와 GND 사이에 연결합니다. 손 접근 센서는 센서 사양에 맞춰 VCC와 GND를 먼저 연결하고, 센서 GND와 ESP32 GND를 공통으로 만든 뒤 디지털 출력만 GPIO 21에 연결합니다. 출력은 반드시 3.3 V GPIO 호환이어야 하며 5 V 출력 센서는 레벨 시프터를 거칩니다.
- GPIO 19/GPIO 21은 기본적으로 pull-up이므로, active-low 설정에서는 GND 쪽 입력이 감지 상태입니다. 센서 종류가 바뀌면 `MOUNT_SENSOR_ACTIVE_LOW`, `HAND_SENSOR_ACTIVE_LOW`, `SENSOR_STABLE_SAMPLES`만 조정합니다.
- 서보 전원은 안정적인 5 V를 사용하고 ESP32와 GND를 공통으로 연결합니다. 서보를 ESP32 3.3 V 핀에서 구동하지 마세요. 배선 변경과 각도 보정은 전원을 끈 상태에서 하고, 처음 잠금 시험은 스마트폰을 넣지 않은 상태에서 합니다.
- 이 검증 범위는 BLE, 센서, 서보 잠금만 다룹니다.

## BLE 프로토콜

| 항목 | 값 |
|---|---|
| Device name | `WOLI-DT01` |
| Service | `7e7a0001-1f5f-4c2b-9b6f-2d1b7f4f0100` |
| Command | `7e7a0002-1f5f-4c2b-9b6f-2d1b7f4f0100` — UTF-8 WRITE |
| Status | `7e7a0003-1f5f-4c2b-9b6f-2d1b7f4f0100` — READ + NOTIFY |

명령은 `LOCK`, `UNLOCK`, `START`, `SESSION_END`, `STOP`, `STATUS`, `CAL_LOCK=90`, `CAL_UNLOCK=10`입니다.

- `START`: 집중 세션을 활성화하고 잠급니다.
- `SESSION_END`: 정상 집중 완료를 알리고 세션을 비활성화한 뒤 잠금을 풉니다.
- `STOP`: 비정상 종료/호환용 명령입니다. 앱의 중도 종료는 기존 미션 흐름을 먼저 따라야 합니다.
- `STATUS`: 현재 상태를 즉시 보냅니다.

상태 형식은 `mount=1;lock=1;hand=0;battery=100;session=1`입니다. 각 값은 `mount`(거치), `lock`(잠금), `hand`(손 접근), `session`(집중 세션)이 `0` 또는 `1`이고 `battery`는 0~100입니다. 상태 변경/명령 처리 시 즉시 Notify되고, 변경이 없어도 약 1초마다 heartbeat가 올 수 있습니다.

## STEP 1–15: Android 앱 실기기 검증

1. **ESP32 USB 연결**: ESP32-WROOM-32를 USB로 연결하고 보드가 인식되는지 확인합니다.
2. **펌웨어 업로드**: `firmware`에서 `pio pkg install`, `pio run -t upload`를 실행합니다.
3. **Serial Monitor 115200**: `pio device monitor -b 115200`을 열어 로그를 확인합니다.
4. **Advertising 확인**: `[WOLI][BOOT] firmware ready`와 `[WOLI][BLE] advertising started` 뒤에 `WOLI-DT01`이 검색되는지 확인합니다.
5. **Android 앱 실행**: Android 실기기에서 월이 앱을 열고 Bluetooth 권한을 허용합니다.
6. **월이 기기 검색**: 기기 연결 화면에서 `WOLI-DT01`을 찾습니다.
7. **연결**: 기기를 선택해 연결하고, Service Discovery와 Status Notify 등록이 끝날 때까지 기다립니다.
8. **STATUS 확인**: 하드웨어 진단 화면에서 `STATUS`를 실행합니다. 표시된 mount/lock/hand/battery/session 값과 Serial의 `[WOLI][STATUS]` payload가 일치해야 합니다.
9. **스마트폰 거치 센서 테스트**: GPIO 19 스위치를 동작시켜 `mount=0`과 `mount=1` Notify가 즉시 반영되는지 확인합니다.
10. **START 전송**: 앱의 최소 집중 시간은 5분입니다. 시연에서는 시작 직후 화면의 완료 기능을 쓰거나, 5분 타이머로 시작합니다. 예상 상태는 `lock=1`, `session=1`이며 Serial에는 `[WOLI][CMD] START`, `[WOLI][SESSION] active=1`, `[WOLI][LOCK] 0 -> 1`가 표시됩니다.
11. **손 접근**: GPIO 21 센서를 감지 상태로 만듭니다. `hand=1` Notify, Android 손 접근 경고 화면, 세션 `handWarningCount +1`이 보여야 합니다.
12. **손 계속 유지**: 감지 상태를 유지합니다. heartbeat가 와도 경고 횟수는 추가로 증가하지 않아야 합니다.
13. **손 제거**: 센서를 비감지 상태로 돌립니다. `hand=0` Notify 뒤 앱은 버튼 조작 없이 기본 집중 눈 화면으로 돌아와야 합니다.
14. **다시 손 접근**: 다시 `hand=1`로 바꿉니다. 이번에는 경고 횟수가 정확히 한 번 더 증가해야 합니다.
15. **세션 정상 종료**: 5분 타이머가 0이 되도록 기다리거나 시연용 완료 기능을 사용합니다. 앱은 `SESSION_END`를 보내고, `lock=0`, `session=0`, `FocusCompleteScreen`, 세션 리포트가 차례로 보여야 합니다.

## 연결 해제와 재연결

집중 중 앱의 연결을 끊어도 앱 타이머와 세션 기록은 유지되어야 합니다. Serial에서 `[WOLI][BLE] client disconnected; advertising restart enabled`를 확인한 뒤, 앱에서 같은 `WOLI-DT01`을 다시 연결합니다. 재연결 후 Status Notify 등록과 최초 READ(READ 실패 시 `STATUS`) 동기화로 현재 mount/lock/hand/battery/session 값이 다시 표시되어야 합니다. 정상 완료 중 연결이 끊겼다면 재연결 뒤 보류된 `SESSION_END`가 전송되어 `lock=0;session=0`으로 복구되는지 확인합니다. 무한 재연결을 기다리지 말고, 실패 시 Bluetooth를 한 번 껐다 켠 뒤 수동 재연결합니다.

대표 Serial 로그는 다음과 같습니다.

```text
[WOLI][BOOT] firmware ready
[WOLI][BLE] advertising started
[WOLI][BLE] client connected
[WOLI][CMD] START
[WOLI][SESSION] active=1
[WOLI][HAND] 0 -> 1
[WOLI][STATUS] mount=1;lock=1;hand=1;battery=100;session=1
[WOLI][BLE] client disconnected
```

## nRF Connect로 ESP32만 분리 검증

Android 앱 문제가 아닌지 확인할 때는 nRF Connect 같은 일반 BLE GATT 클라이언트를 사용합니다.

1. `WOLI-DT01`을 Scan 후 Connect합니다.
2. WOLI Service를 열고 Status Characteristic에서 **Read**를 실행한 뒤 **Notify**를 구독합니다.
3. Command Characteristic에 UTF-8 텍스트로 `STATUS`를 Write합니다. Status가 즉시 갱신되는지 확인합니다.
4. `START`를 Write해 `lock=1;session=1`을 확인합니다.
5. `SESSION_END`를 Write해 `lock=0;session=0`을 확인합니다.
6. `LOCK`, `UNLOCK`도 각각 Write해 잠금 값과 Notify를 확인합니다.

기대 payload 예시는 다음과 같습니다.

```text
mount=1;lock=1;hand=0;battery=100;session=1
```

센서/서보를 연결하지 않은 개발 보드에서는 pull-up 기본 상태에 따라 `mount=0`, `hand=0`이 정상이며, 배터리 ADC를 사용하지 않으면 `battery=100`이 정상입니다.

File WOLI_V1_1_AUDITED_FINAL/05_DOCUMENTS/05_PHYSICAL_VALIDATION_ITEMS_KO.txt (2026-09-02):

WOLI V1.1 실물 검증 필요 항목
==============================

1. Phone Ball
Ø16.0mm
- 실제 socket fit 필요
- 필요 시 15.8 / 16.2mm 수정

2. Servo Lock
- Stock horn 실제 hole/screw
- Blocking point
- 18/22/26/30mm 중 적합 reach
- LOCK 90° / UNLOCK 10°는 firmware reference

3. N20 / Ground Clearance
- 실제 metal bracket 조립 시 shaft 높이
- chassis 바닥의 실제 지상고

4. Ball Caster
- clip-fit
- wheel 2개와 caster 1개가 동시에 접지되는지
- caster가 너무 낮으면 1/2/3mm shim으로 올릴 수 있음
- caster가 바닥에 닿지 않으면 shim이 아니라 cartridge drop 재설계 필요

5. USB-C
- Board holder fit
- 13B USB-C hatch는 TEST
- connector shell 위치 확인 후 외부 port 최종 승인

6. Stability
- Battery 약205g는 CAD 배치에 반영
- Smartphone + commercial holder 실제 질량은 미확정
- 급정지/회전/잠금 동작에서 전복 테스트 필요

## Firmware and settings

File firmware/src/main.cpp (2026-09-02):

/**
 * WOLI ESP32 firmware.
 *
 * BLE GATT protocol:
 * - service  7e7a0001-1f5f-4c2b-9b6f-2d1b7f4f0100
 * - command  7e7a0002-1f5f-4c2b-9b6f-2d1b7f4f0100  WRITE
 * - status   7e7a0003-1f5f-4c2b-9b6f-2d1b7f4f0100  READ/NOTIFY
 *
 * Status payload: mount=1;lock=0;hand=0;battery=100;session=0
 * Commands: LOCK, UNLOCK, START, SESSION_END, STOP, STATUS, HAND_NEAR,
 * HAND_FAR, CAL_LOCK=90, CAL_UNLOCK=10
 *
 * Hand approach is driven by the phone camera over BLE (HAND_NEAR/HAND_FAR).
 * N20 wheel motors retreat on HAND_NEAR and return on HAND_FAR or session end.
 */
#include <Arduino.h>
#include <ESP32Servo.h>
#include <NimBLEDevice.h>

#ifndef SERVO_PIN
#define SERVO_PIN 13
#endif

#ifndef LIMIT_SWITCH_PIN
#define LIMIT_SWITCH_PIN -1
#endif

#ifndef MOTOR_LEFT_IN1
#define MOTOR_LEFT_IN1 16
#endif

#ifndef MOTOR_LEFT_IN2
#define MOTOR_LEFT_IN2 17
#endif

#ifndef MOTOR_RIGHT_IN3
#define MOTOR_RIGHT_IN3 18
#endif

#ifndef MOTOR_RIGHT_IN4
#define MOTOR_RIGHT_IN4 19
#endif

#ifndef MOVE_TIME_MS
#define MOVE_TIME_MS 600
#endif

#ifndef BATTERY_ADC_PIN
#define BATTERY_ADC_PIN -1
#endif

#ifndef SERVO_MIN_US
#define SERVO_MIN_US 500
#endif

#ifndef SERVO_MAX_US
#define SERVO_MAX_US 2400
#endif

#ifndef LOCK_SERVO_DEGREES
#define LOCK_SERVO_DEGREES 90
#endif

#ifndef UNLOCK_SERVO_DEGREES
#define UNLOCK_SERVO_DEGREES 10
#endif

#ifndef MOUNT_SENSOR_ACTIVE_LOW
#define MOUNT_SENSOR_ACTIVE_LOW 1
#endif

#ifndef SENSOR_STABLE_SAMPLES
#define SENSOR_STABLE_SAMPLES 4
#endif

#ifndef STATUS_INTERVAL_MS
#define STATUS_INTERVAL_MS 1000
#endif

static const char *DEVICE_NAME = "WOLI-DT01";
static const char *SERVICE_UUID = "7e7a0001-1f5f-4c2b-9b6f-2d1b7f4f0100";
static const char *COMMAND_UUID = "7e7a0002-1f5f-4c2b-9b6f-2d1b7f4f0100";
static const char *STATUS_UUID = "7e7a0003-1f5f-4c2b-9b6f-2d1b7f4f0100";

struct DebouncedInput {
  uint8_t pin;
  bool activeLow;
  bool stableValue = false;
  bool candidateValue = false;
  uint8_t candidateCount = 0;

  DebouncedInput(uint8_t inputPin, bool inputActiveLow)
      : pin(inputPin), activeLow(inputActiveLow) {}

  bool readRaw() const {
    const bool high = digitalRead(pin) == HIGH;
    return activeLow ? !high : high;
  }

  void syncInitial() {
    stableValue = readRaw();
    candidateValue = stableValue;
    candidateCount = SENSOR_STABLE_SAMPLES;
  }

  bool update() {
    const bool next = readRaw();
    if (next == candidateValue) {
      if (candidateCount < SENSOR_STABLE_SAMPLES) {
        candidateCount++;
      }
    } else {
      candidateValue = next;
      candidateCount = 1;
    }

    if (candidateCount >= SENSOR_STABLE_SAMPLES && stableValue != candidateValue) {
      stableValue = candidateValue;
      return true;
    }
    return false;
  }
};

static NimBLECharacteristic *statusCharacteristic = nullptr;
static Servo lockServo;
#if LIMIT_SWITCH_PIN >= 0
static DebouncedInput mountSensor(LIMIT_SWITCH_PIN, MOUNT_SENSOR_ACTIVE_LOW == 1);
#endif
static bool locked = false;
static bool mounted = false;
static bool handNear = false;
static bool sessionActive = false;
static bool isRetreated = false;
static uint8_t batteryPercent = 100;
static int lockDegrees = LOCK_SERVO_DEGREES;
static int unlockDegrees = UNLOCK_SERVO_DEGREES;

static bool motorsEnabled() {
  return MOTOR_LEFT_IN1 >= 0 && MOTOR_LEFT_IN2 >= 0 && MOTOR_RIGHT_IN3 >= 0 &&
         MOTOR_RIGHT_IN4 >= 0;
}

static void stopMotors() {
  if (!motorsEnabled()) {
    return;
  }
  digitalWrite(MOTOR_LEFT_IN1, LOW);
  digitalWrite(MOTOR_LEFT_IN2, LOW);
  digitalWrite(MOTOR_RIGHT_IN3, LOW);
  digitalWrite(MOTOR_RIGHT_IN4, LOW);
}

static void moveBackward() {
  if (!motorsEnabled()) {
    return;
  }
  Serial.println("[WOLI][MOTOR] retreat backward");
  digitalWrite(MOTOR_LEFT_IN1, LOW);
  digitalWrite(MOTOR_LEFT_IN2, HIGH);
  digitalWrite(MOTOR_RIGHT_IN3, LOW);
  digitalWrite(MOTOR_RIGHT_IN4, HIGH);
  delay(MOVE_TIME_MS);
  stopMotors();
}

static void moveForward() {
  if (!motorsEnabled()) {
    return;
  }
  Serial.println("[WOLI][MOTOR] return forward");
  digitalWrite(MOTOR_LEFT_IN1, HIGH);
  digitalWrite(MOTOR_LEFT_IN2, LOW);
  digitalWrite(MOTOR_RIGHT_IN3, HIGH);
  digitalWrite(MOTOR_RIGHT_IN4, LOW);
  delay(MOVE_TIME_MS);
  stopMotors();
}

static uint8_t readBatteryPercent() {
#if BATTERY_ADC_PIN >= 0
  const int raw = analogRead(BATTERY_ADC_PIN);
  const int percent = map(raw, 0, 4095, 0, 100);
  return constrain(percent, 0, 100);
#else
  return batteryPercent;
#endif
}

static String statusPayload() {
  return String("mount=") + (mounted ? "1" : "0") +
         ";lock=" + (locked ? "1" : "0") +
         ";hand=" + (handNear ? "1" : "0") +
         ";battery=" + String(batteryPercent) +
         ";session=" + (sessionActive ? "1" : "0");
}

static void notifyStatus(bool logStatus = true) {
  if (statusCharacteristic == nullptr) {
    return;
  }

  batteryPercent = readBatteryPercent();
  const String payload = statusPayload();
  statusCharacteristic->setValue(payload.c_str());
  if (statusCharacteristic->getSubscribedCount() > 0) {
    statusCharacteristic->notify();
  }
  if (logStatus) {
    Serial.printf("[WOLI][STATUS] %s\n", payload.c_str());
  }
}

static void applyServoAngle(int angle) {
  lockServo.write(constrain(angle, 0, 180));
}

static void releaseRetreatIfNeeded() {
  if (!isRetreated) {
    return;
  }
  moveForward();
  isRetreated = false;
}

static void setHandNear(bool near, bool allowRetreatMotion) {
  if (handNear == near) {
    return;
  }

  const bool wasHandNear = handNear;
  handNear = near;
  Serial.printf("[WOLI][HAND] %d -> %d\n", wasHandNear ? 1 : 0, handNear ? 1 : 0);

  if (!allowRetreatMotion || !sessionActive) {
    notifyStatus();
    return;
  }

  if (handNear && !isRetreated) {
    moveBackward();
    isRetreated = true;
  } else if (!handNear && isRetreated) {
    moveForward();
    isRetreated = false;
  }
  notifyStatus();
}

static void setSessionActive(bool active) {
  if (sessionActive == active) {
    return;
  }

  sessionActive = active;
  Serial.printf("[WOLI][SESSION] active=%d\n", sessionActive ? 1 : 0);
}

static void endSession() {
  setSessionActive(false);
  releaseRetreatIfNeeded();
  handNear = false;
  setLock(false);
}

static void setLock(bool enable) {
  const bool wasLocked = locked;
  locked = enable;
  applyServoAngle(enable ? lockDegrees : unlockDegrees);
  if (wasLocked != locked) {
    Serial.printf("[WOLI][LOCK] %d -> %d angle=%d\n", wasLocked ? 1 : 0,
                  locked ? 1 : 0, enable ? lockDegrees : unlockDegrees);
  }
  notifyStatus();
}

static bool updateCalibration(const String &command, const char *prefix, int *target) {
  if (!command.startsWith(prefix)) {
    return false;
  }

  const int value = command.substring(strlen(prefix)).toInt();
  *target = constrain(value, 0, 180);
  Serial.printf("[WOLI][CAL] %s%d\n", prefix, *target);
  setLock(locked);
  return true;
}

static void handleCommand(const String &rawCommand) {
  String command = rawCommand;
  command.trim();
  command.toUpperCase();

  Serial.printf("[WOLI][CMD] %s\n", command.c_str());

  if (command == "START") {
    isRetreated = false;
    handNear = false;
    setSessionActive(true);
    setLock(true);
    return;
  }
  if (command == "SESSION_END" || command == "STOP") {
    endSession();
    return;
  }
  if (command == "LOCK") {
    setLock(true);
    return;
  }
  if (command == "UNLOCK") {
    setLock(false);
    return;
  }
  if (command == "HAND_NEAR") {
    setHandNear(true, true);
    return;
  }
  if (command == "HAND_FAR") {
    setHandNear(false, true);
    return;
  }
  if (command == "STATUS") {
    notifyStatus();
    return;
  }
  if (updateCalibration(command, "CAL_LOCK=", &lockDegrees)) {
    return;
  }
  if (updateCalibration(command, "CAL_UNLOCK=", &unlockDegrees)) {
    return;
  }

  Serial.printf("[WOLI][CMD] unknown=%s\n", command.c_str());
}

class CommandCallbacks : public NimBLECharacteristicCallbacks {
 public:
  void onWrite(NimBLECharacteristic *characteristic) override {
    const std::string value = characteristic->getValue();
    handleCommand(String(value.c_str()));
  }
};

class ServerCallbacks : public NimBLEServerCallbacks {
 public:
  void onConnect(NimBLEServer *) override {
    Serial.println("[WOLI][BLE] client connected");
  }

  void onDisconnect(NimBLEServer *) override {
    Serial.println("[WOLI][BLE] client disconnected; advertising restart enabled");
  }
};

static void setupBle() {
  NimBLEDevice::init(DEVICE_NAME);
  NimBLEServer *server = NimBLEDevice::createServer();
  server->setCallbacks(new ServerCallbacks());
  server->advertiseOnDisconnect(true);
  NimBLEService *service = server->createService(SERVICE_UUID);

  NimBLECharacteristic *commandCharacteristic = service->createCharacteristic(
      COMMAND_UUID,
      NIMBLE_PROPERTY::WRITE | NIMBLE_PROPERTY::WRITE_NR);
  commandCharacteristic->setCallbacks(new CommandCallbacks());

  statusCharacteristic = service->createCharacteristic(
      STATUS_UUID,
      NIMBLE_PROPERTY::READ | NIMBLE_PROPERTY::NOTIFY);
  statusCharacteristic->setValue(statusPayload().c_str());

  service->start();

  NimBLEAdvertising *advertising = NimBLEDevice::getAdvertising();
  advertising->addServiceUUID(SERVICE_UUID);
  advertising->setScanResponse(true);
  if (advertising->start()) {
    Serial.println("[WOLI][BLE] advertising started");
  } else {
    Serial.println("[WOLI][BLE] advertising start failed");
  }
}

static void setupMotors() {
  if (!motorsEnabled()) {
    Serial.println("[WOLI][BOOT] wheel motors disabled");
    return;
  }

  pinMode(MOTOR_LEFT_IN1, OUTPUT);
  pinMode(MOTOR_LEFT_IN2, OUTPUT);
  pinMode(MOTOR_RIGHT_IN3, OUTPUT);
  pinMode(MOTOR_RIGHT_IN4, OUTPUT);
  stopMotors();
  Serial.printf("[WOLI][BOOT] wheel motors ready moveMs=%d\n", MOVE_TIME_MS);
}

void setup() {
  Serial.begin(115200);
  Serial.println("[WOLI][BOOT] starting");
#if LIMIT_SWITCH_PIN >= 0
  pinMode(LIMIT_SWITCH_PIN, INPUT_PULLUP);
  mountSensor.syncInitial();
  mounted = mountSensor.stableValue;
#else
  mounted = true;
#endif
#if BATTERY_ADC_PIN >= 0
  pinMode(BATTERY_ADC_PIN, INPUT);
#endif

  batteryPercent = readBatteryPercent();
  Serial.printf("[WOLI][BOOT] mount=%d hand=%d battery=%u\n", mounted ? 1 : 0,
                handNear ? 1 : 0, static_cast<unsigned>(batteryPercent));

  ESP32PWM::allocateTimer(0);
  lockServo.setPeriodHertz(50);
  lockServo.attach(SERVO_PIN, SERVO_MIN_US, SERVO_MAX_US);
  setLock(false);
  setupMotors();
  setupBle();
  Serial.println("[WOLI][BOOT] firmware ready");
}

void loop() {
#if LIMIT_SWITCH_PIN >= 0
  if (mountSensor.update()) {
    const bool wasMounted = mounted;
    mounted = mountSensor.stableValue;
    Serial.printf("[WOLI][MOUNT] %d -> %d\n", wasMounted ? 1 : 0, mounted ? 1 : 0);
    notifyStatus();
  }
#endif

  static uint32_t lastHeartbeat = 0;
  const uint32_t now = millis();
  if (now - lastHeartbeat >= STATUS_INTERVAL_MS) {
    lastHeartbeat = now;
    notifyStatus(false);
  }

  delay(25);
}

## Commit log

2026-08-01 Add WOLI Android UI shells and ESP32 firmware skeleton.
    Scaffold Compose screens from the SW scenario, document setup in README, and ignore the unrelated large zip archive.
2026-08-01 Add emulator screenshots and README current screen status section.
    Capture all UI shell screens into docs/screenshots and document them for onboarding.
2026-08-09 알림 접근 권한 허용
2026-08-09 음성 답장 전송 연결
2026-08-10 집중 중 알림 답장 및 전화 감지 연결
2026-08-10 집중 모드 핵심 기능 완성
2026-08-11 실기기 검증 개선 추가
2026-08-11 Fix focus exit navigation and redesign hand-warning eyes.
    Keep teammate focus/device features while clearing the session stack on complete/quit and updating angry eyes plus the anger mark badge.
2026-08-12 feat(focus): 중도 해제 방지 미션을 리듬게임으로 교체
    기획안 4.5 "행동 마찰 장치"를 정통 리듬게임으로 구현한다.
    기존 화면은 정해진 순서대로 레인을 탭하는 방식이라 리듬게임이 아니었고,
    노트가 낙하해 판정선에서 타이밍을 맞추는 Perfect/Good/Miss 판정으로 바꿨다.
    - focus/WoliRhythmGame.kt: 순수 Kotlin 엔진(차트 생성·판정·점수·통과 규칙).
    시드 기반 결정적 차트라 단위 테스트가 가능하고, 같은 레인 3연속을 막아 실제로 칠 수 있게 한다.
    - ui/screens/RhythmMissionScreen.kt: withFrameNanos 프레임 루프 + Canvas 노트 렌더 + 레인 입력.
    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
2026-08-19 알림 중요도 판단 로직 구현
2026-08-31 집중/전화 화면 UI 개선 및 BLE·권한·펌웨어 업데이트
    전화 수신 정보를 마이크 버튼 위로 재배치하고 남은 시간 화면 문구를 정리했으며, BLE 연결·집중 세션 가드·권한 온보딩과 관련 테스트·문서를 보강했다.
2026-09-01 카메라 손 접근 감지 추가 및 집중 완료·리포트 화면 개선
    MediaPipe 기반 손 접근 감지와 카메라 권한 설정을 추가하고, 집중 완료 후 3초 뒤 리포트로 자동 전환하며 리포트 UI를 실제 집중 시간 중심으로 정리한다.
2026-09-02 ESP32 연동 및 카메라 사용
2026-09-02 집중 세션 보호·리듬 미션 오디오 강화 및 V1.1 하드웨어 릴리즈 추가
    집중 모드 이탈 방지(복구, LockTask, UI 가드), 손 접근·음성 인터럽트, 리듬 미션 배경/타격음·완화 판정을 보강하고 WOLI V1.1 3D 릴리즈 패키지와 화면 캡처를 함께 올린다.
    [01_main_chassis.scad, 01_main_chassis.stl, 03_top_cover.scad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]
